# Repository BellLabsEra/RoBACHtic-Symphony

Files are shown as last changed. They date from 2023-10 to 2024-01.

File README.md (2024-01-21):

# RoBACHtic-Symphony
ECE 3011 Design Fundamentals Project

## Project Description

In the realm of junior-design team initiatives, we undertook a project focused on the development of an educational robot kit. This kit, specifically designed for 5th-grade students, imparts comprehensive knowledge on discerning a violin's bow movement, placement, and techniques—particularly bow posture—while performing musical compositions featuring diverse notes. The device seamlessly integrates with a MIDI piano keyboard, utilizing user input to produce two outputs: a robotic arm executing bow movements corresponding to the "mapped" string and an audio sample replicating the played note.

Comprising a team of four students—three specializing in Electrical Engineering and one in Computer Engineering—we dedicated ourselves to the intricate aspects of Mechanical, Electrical, and Software engineering. In conjunction with the hardware and software components, we meticulously crafted four essential artifacts: a Design Document, Bill of Materials (BOM), Lesson Plan, and Notebook. Notably, our Lesson Plan aligns meticulously with the Georgia Standards of Excellence (GSE) for both Music and Computer Science curricula.

In the context of this collaborative effort, I assumed a leadership role in spearheading the software development aspect of the project. This multifaceted undertaking served as the focal point of our endeavors within the framework of ECE 3011 - Design Fundamentals.

### Link to YouTube Video Demonstration: 
https://youtu.be/gud--ybyr-s?si=2pJu3Hc5zI2o3BWv

### Link to Final Document PDF: 
https://github.com/BellLabsEra/RoBACHtic-Symphony/blob/main/ECE3011%20Team%20C2%20Final%20Document%20Package.pdf

Document containing the (1) Design Document,(2) Lesson Plan, and (3) BOM

### Front View Pictures:

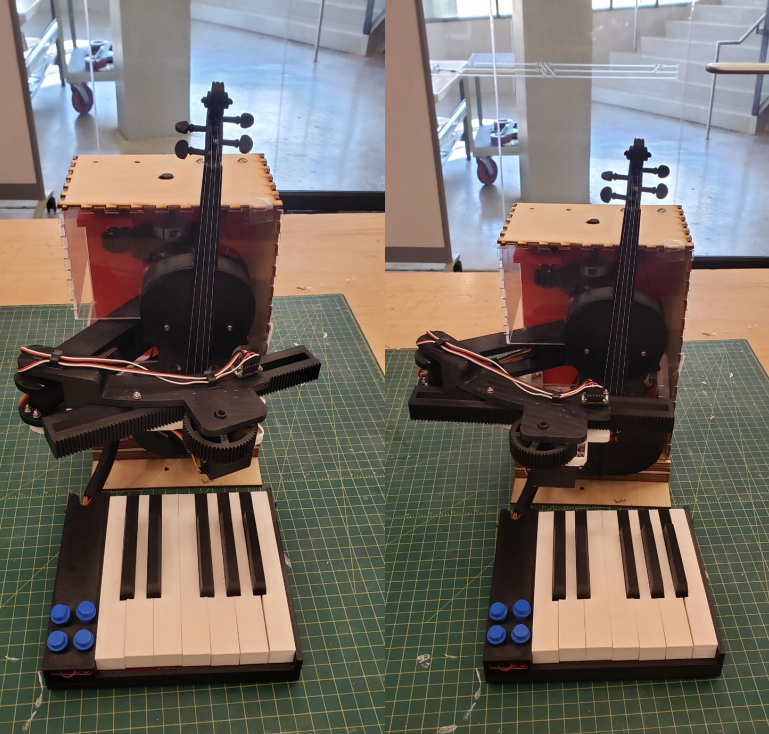
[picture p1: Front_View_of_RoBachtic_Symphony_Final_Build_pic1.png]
Front_View_Pic1


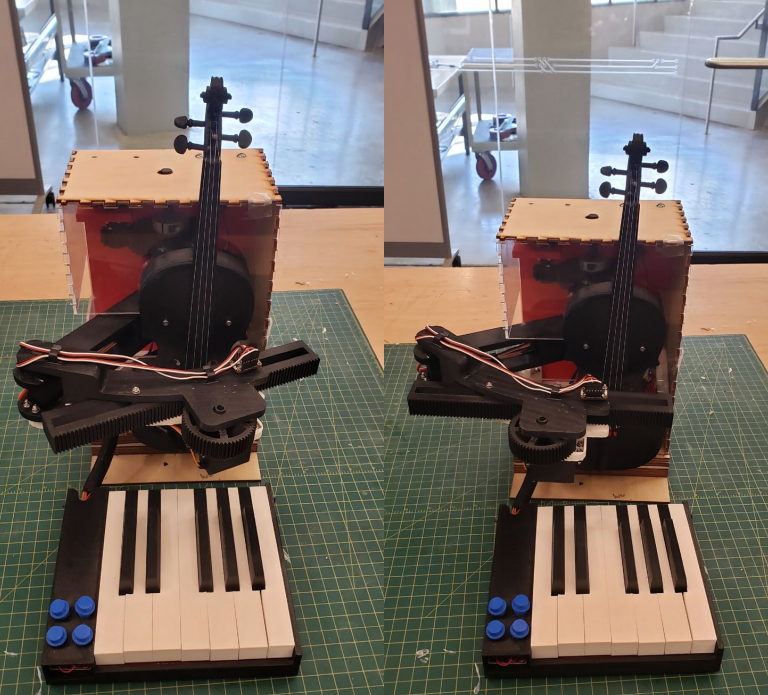
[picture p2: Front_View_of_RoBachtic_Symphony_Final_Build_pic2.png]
Front_View_Pic2


### Labeled Picture:

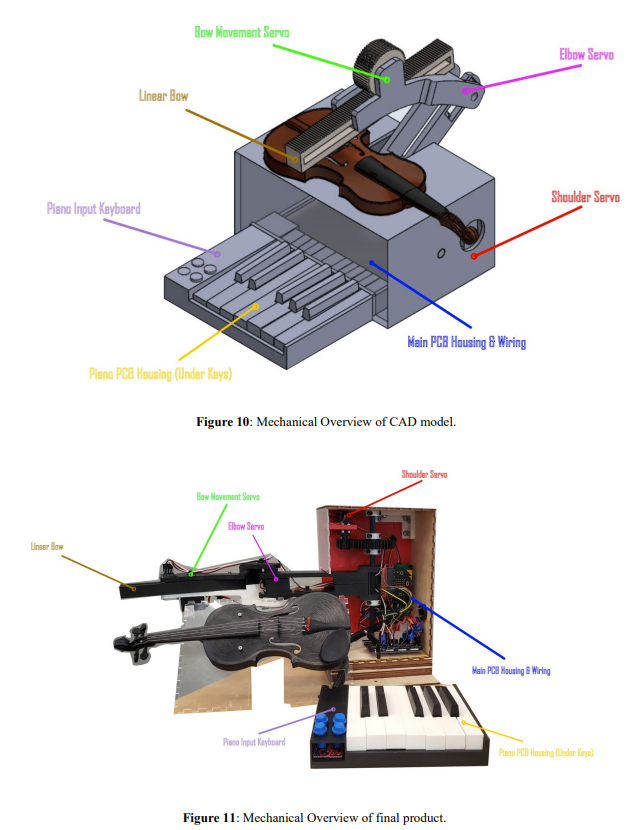
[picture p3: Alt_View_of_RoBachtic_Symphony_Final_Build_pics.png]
Labeled_Picture


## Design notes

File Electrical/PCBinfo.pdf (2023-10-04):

GND1 | Vsupply GND | | V_USED(V) | I_MAX(mA) | I_TOTAL(mA)
GND2 | | PIANO | 3.3 | 8 | 1421
3V3 | IMU,PIANO,MAIN 3.3V | IMU | 3.3 | 5
A0 | PWM SERVO0 | SERVO1 | 6 | 1200 | <-------- | ONLY MOVE ONE AT A TIME
A1 | PWM SERVO1 | SERVO2 | 6 | 0
A2 | PWM SERVO2 | SERVO3 | 6 | 0
A3 | PWM SERVO3 | SERVO4 | 6 | 0
A4 | SPEAKER OUT | LED1 | 3.3 | 2
D5 | LED1 | LED2 | 3.3 | 2
D6 | LED2 | LED3 | 3.3 | 2
D7 | LED3 | LED4 | 3.3 | 2
D8 | LED4 | AMP (0.5W) | 5 | 200
D9
D10 | | | Links
D11 | IMU | https://learn.adafruit.com/adafruit-tdk-invensense-icm-20948-9-dof-imu/pinouts
D12 | IO EXPANDER https://www.digikey.com/en/products/detail/texas-instruments/PCF8575PWE4/1573160
D13 | IMU SCK | SERVOS | https://www.amazon.com/Control-Angle180-Digital-Torque-Helicopter/dp/B07NQJ1VZ2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
D14 | IMU MISO | LEDS | https://www.digikey.com/en/products/detail/sunled/XCMDK12D/13559388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
D15 | IMU MOSI | MONO AMP | https://www.sparkfun.com/products/11044
D16 | IMU CS | PCB PJACK | https://www.sparkfun.com/products/10811
D19 (SCL) | PIANO SCL | VREG | https://www.digikey.com/en/products/detail/stmicroelectronics/LM317T/591677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
D20 (SDA) | PIANO SDA

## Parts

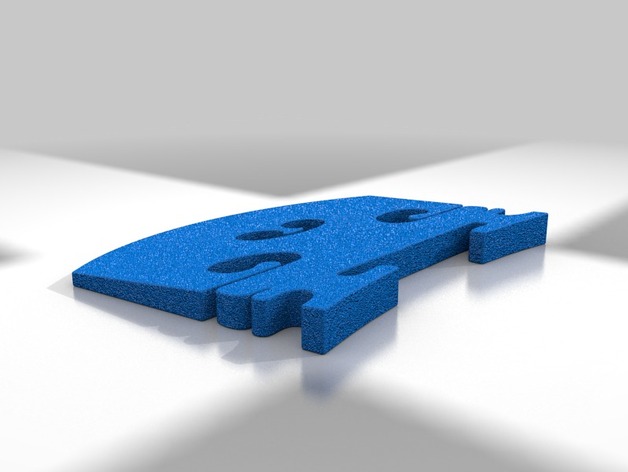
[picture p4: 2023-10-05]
Mechanical Components made by Jeon's blood and tear/images/images/Violin.XIII.Bridge.jpg

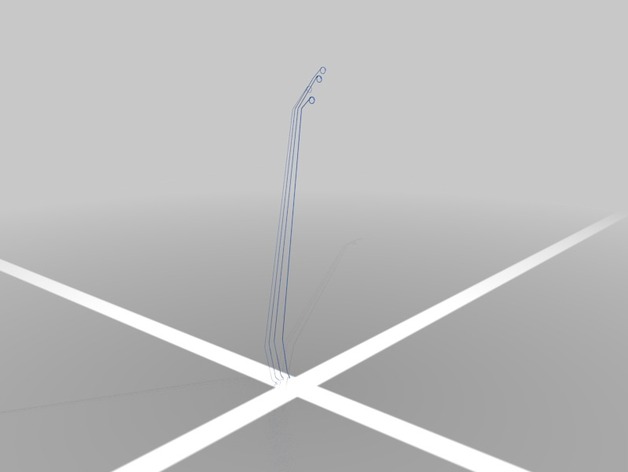
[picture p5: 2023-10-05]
Mechanical Components made by Jeon's blood and tear/images/images/Violin.XIII.Strings.jpg

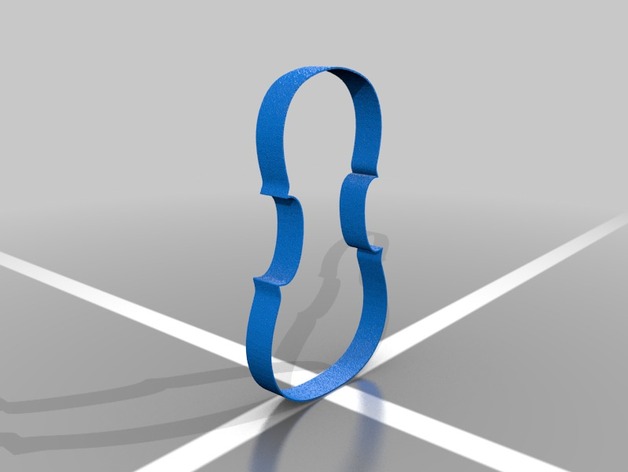
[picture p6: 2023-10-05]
Mechanical Components made by Jeon's blood and tear/images/images/Violin.XIII.Side.jpg

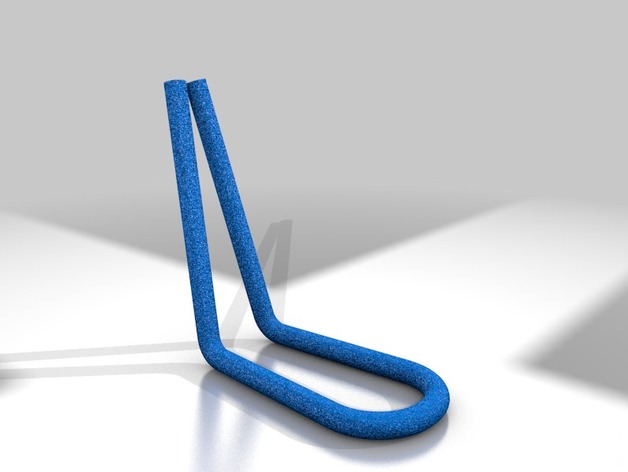
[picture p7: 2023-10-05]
Mechanical Components made by Jeon's blood and tear/images/images/Violin.XIII.Tail.Cord.jpg

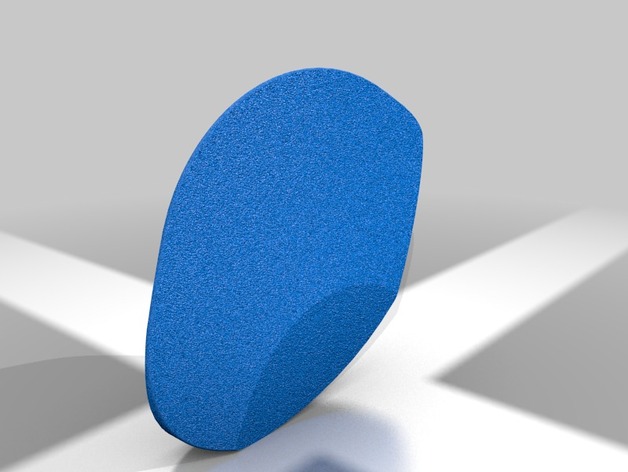
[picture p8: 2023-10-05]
Mechanical Components made by Jeon's blood and tear/images/images/Violin.XIII.Chin.Rest.jpg

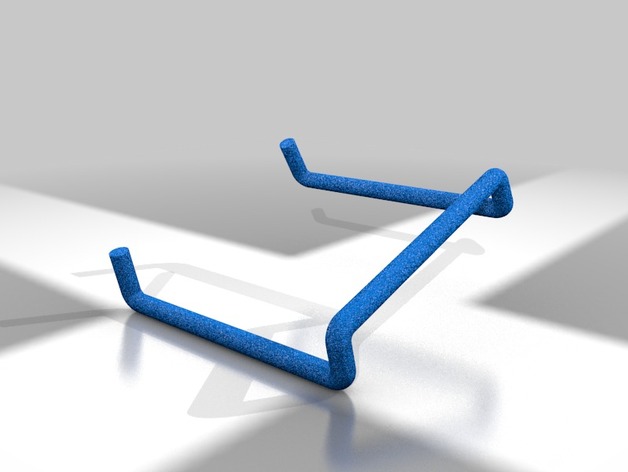
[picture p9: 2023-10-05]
Mechanical Components made by Jeon's blood and tear/images/images/Violin.XIII.Chin.Rest.Clamp.jpg

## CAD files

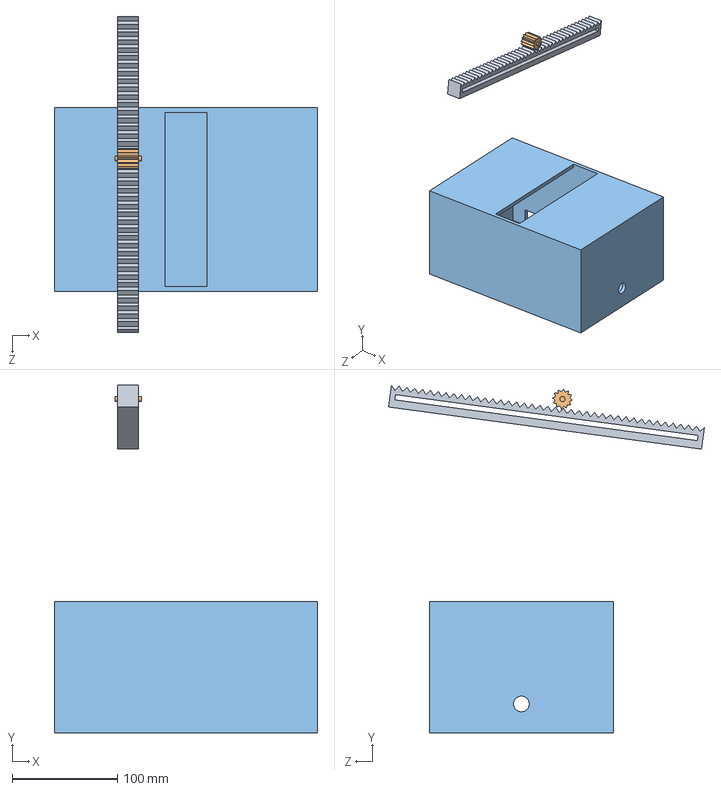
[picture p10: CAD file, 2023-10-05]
Mechanical Components made by Jeon's blood and tear/Prototype_x.SLDASM
250.0 x 330.4 x 300.1 mm
Gear
Bow

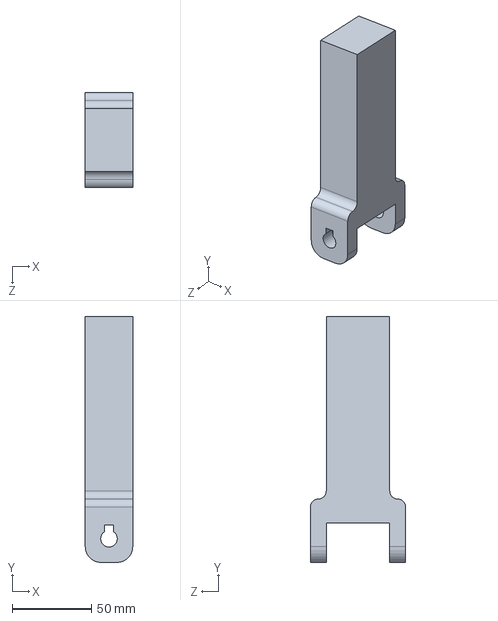
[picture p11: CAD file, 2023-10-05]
Mechanical Components made by Jeon's blood and tear/Arms/Part_Files/MainArm.SLDPRT
30.0 x 155.0 x 60.0 mm

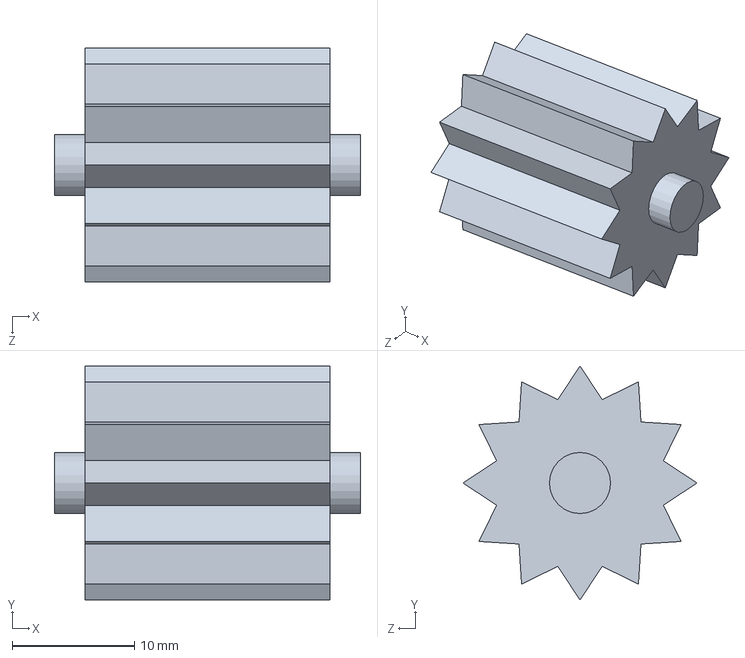
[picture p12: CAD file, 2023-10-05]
Mechanical Components made by Jeon's blood and tear/Arms/Gear.SLDPRT
25.0 x 19.1 x 19.1 mm

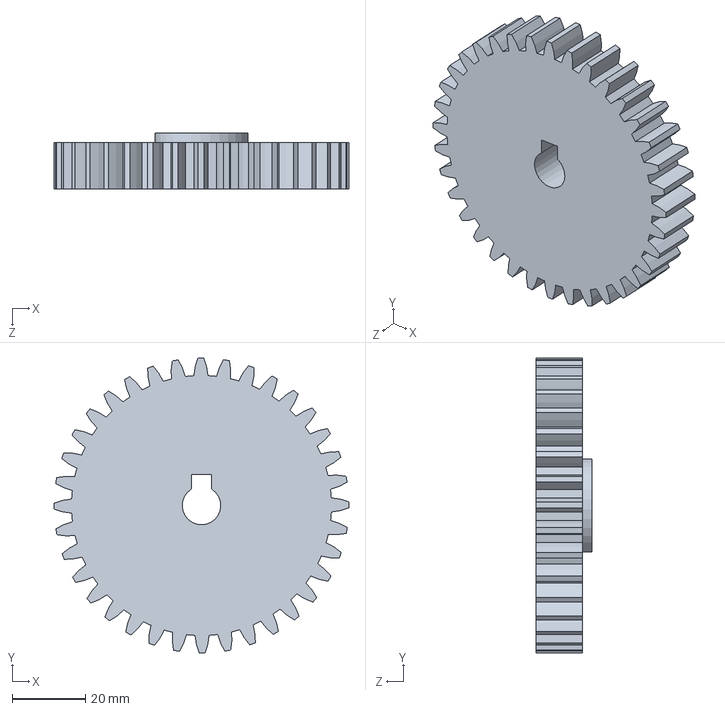
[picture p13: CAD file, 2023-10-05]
Mechanical Components made by Jeon's blood and tear/Arms/Part_Files/LargeGear.SLDPRT
80.4 x 80.4 x 15.2 mm

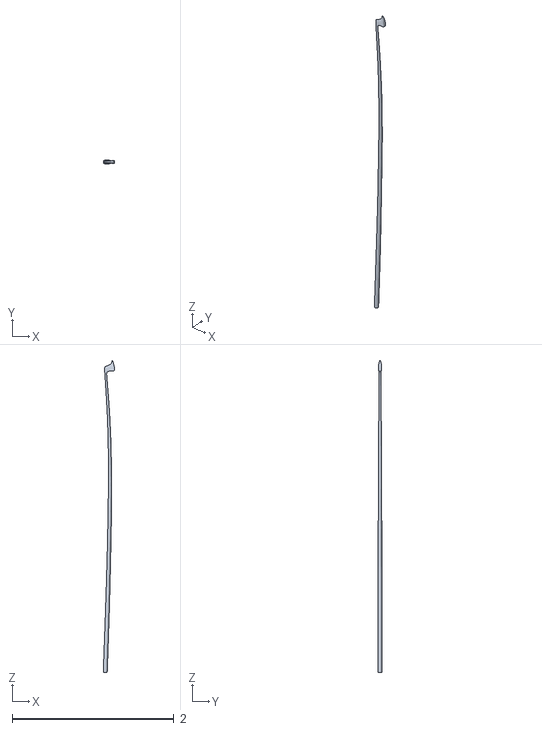
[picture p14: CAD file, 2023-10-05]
Mechanical Components made by Jeon's blood and tear/files/files/Violin.XIII.Bow.Rod.stl
0.142 x 0.0497 x 3.86

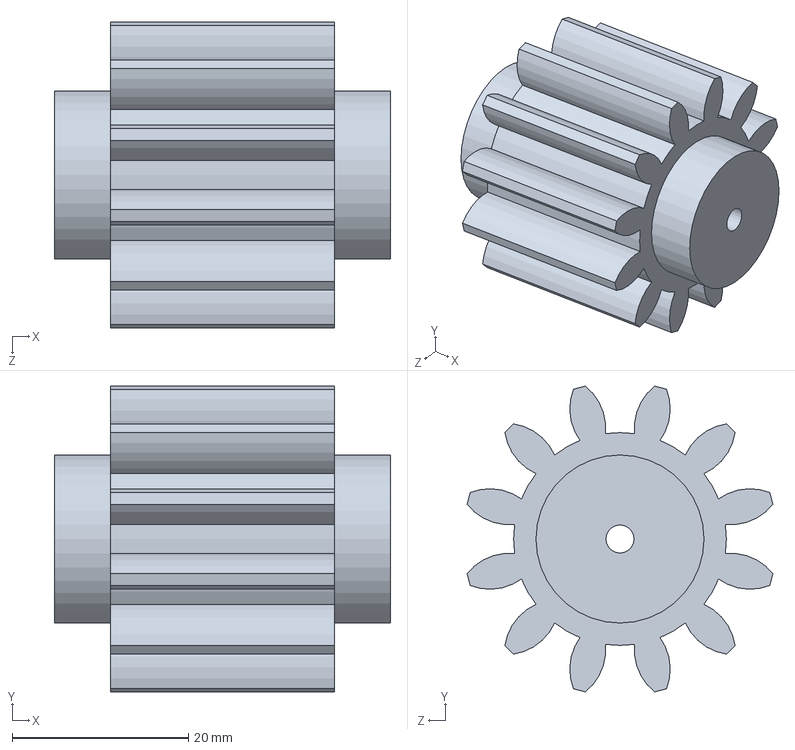
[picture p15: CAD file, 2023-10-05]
Mechanical Components made by Jeon's blood and tear/GearboxMod/SmallGear.SLDPRT
38.1 x 34.7 x 34.7 mm

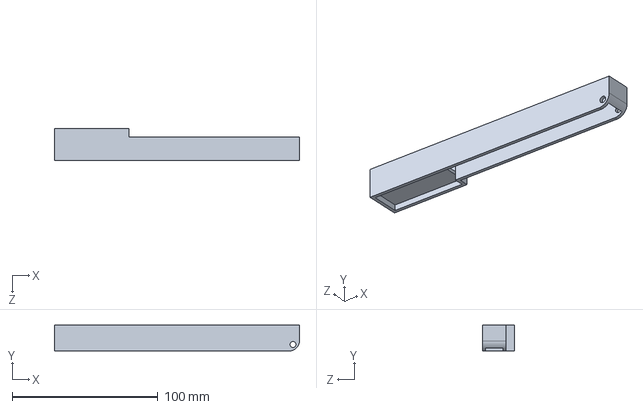
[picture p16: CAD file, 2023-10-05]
Mechanical Components made by Jeon's blood and tear/Keyboard/SLDPRT/White Key L.SLDPRT
168.0 x 17.8 x 22.0 mm

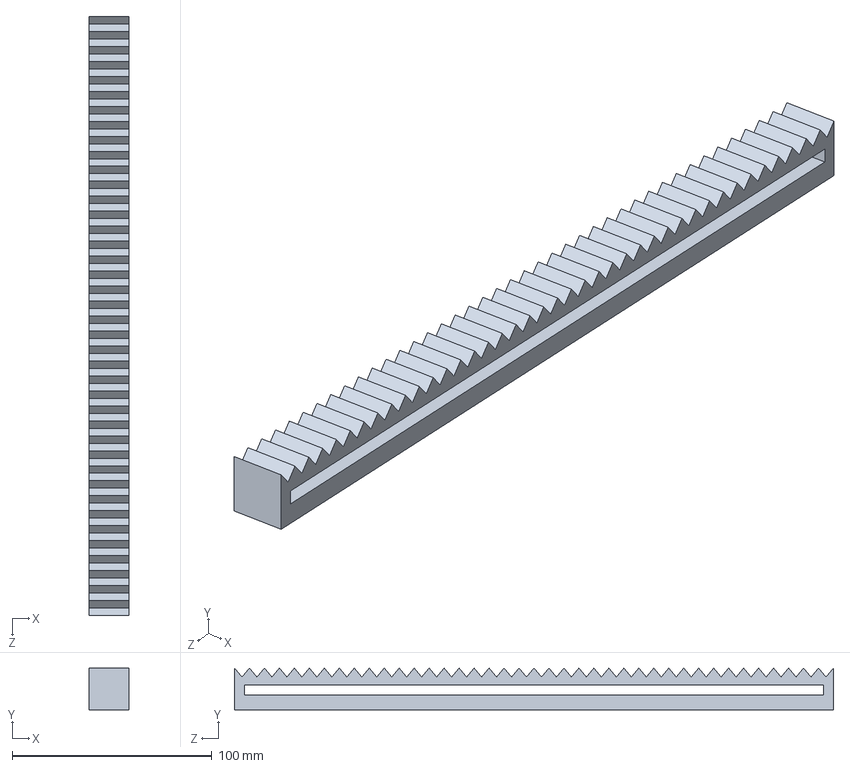
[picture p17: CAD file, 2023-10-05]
Mechanical Components made by Jeon's blood and tear/Arms/Bow.SLDPRT
20.0 x 21.0 x 300.0 mm

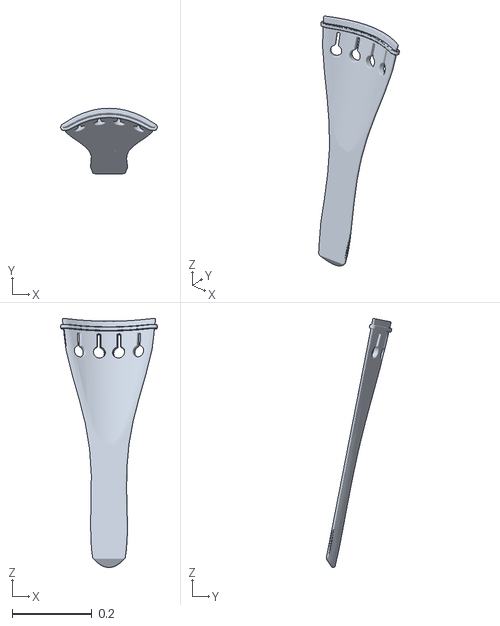
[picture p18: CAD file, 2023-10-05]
Mechanical Components made by Jeon's blood and tear/files/files/Violin.XIII.Tail.Piece.stl
0.243 x 0.165 x 0.626

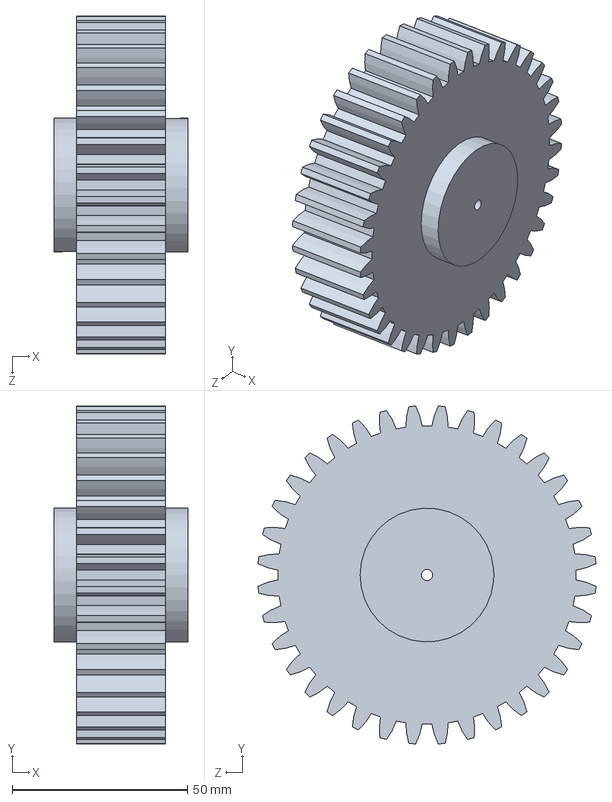
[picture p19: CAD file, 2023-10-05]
Mechanical Components made by Jeon's blood and tear/GearboxMod/LargeGear.SLDPRT
38.1 x 96.3 x 96.3 mm

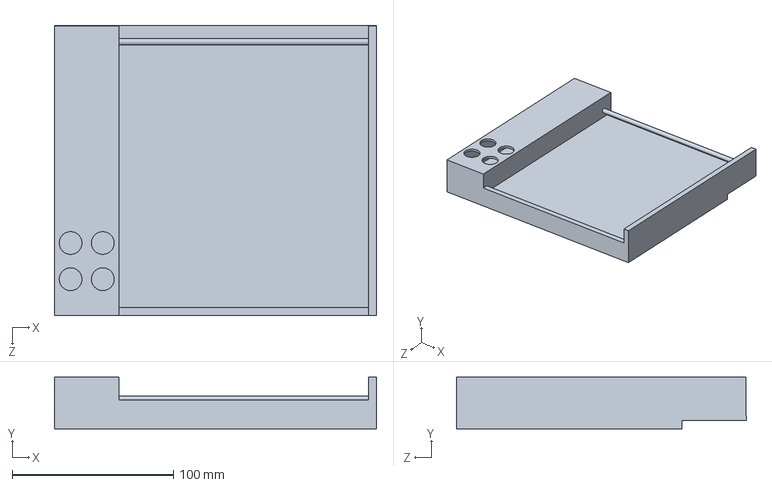
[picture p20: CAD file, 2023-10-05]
Mechanical Components made by Jeon's blood and tear/Keyboard/SLDPRT/Keyboard Box.SLDPRT
200.0 x 32.0 x 180.0 mm

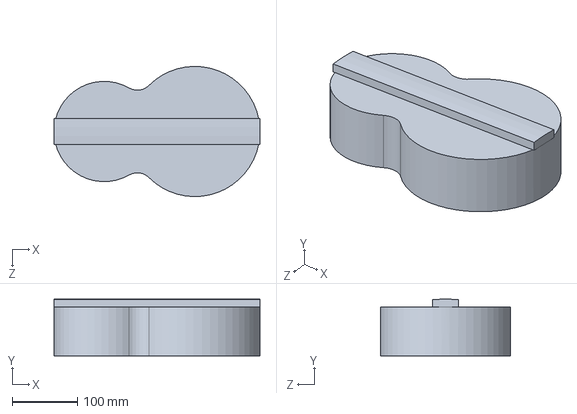
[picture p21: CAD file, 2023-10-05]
Mechanical Components made by Jeon's blood and tear/Violin_x.SLDPRT
316.5 x 87.1 x 200.0 mm

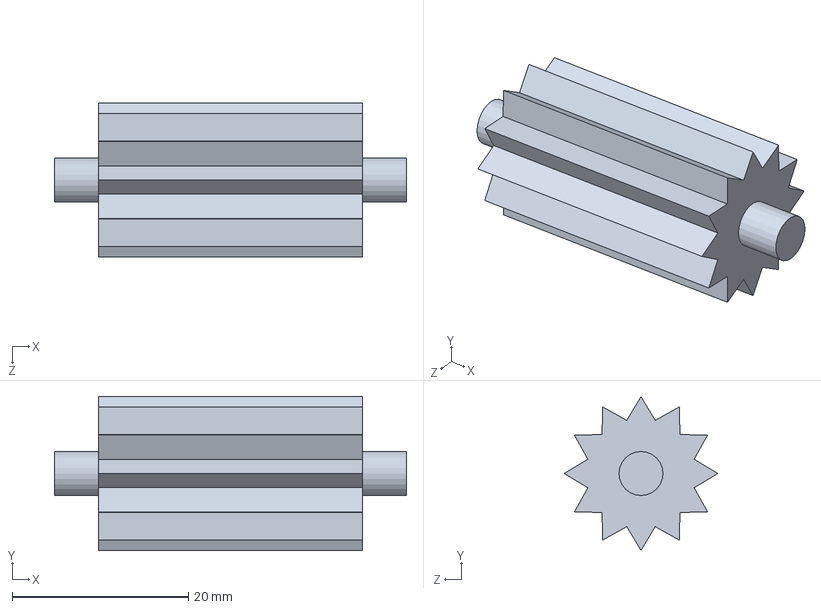
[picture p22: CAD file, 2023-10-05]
Mechanical Components made by Jeon's blood and tear/Arms/Gear_x.SLDPRT
40.0 x 17.5 x 17.5 mm

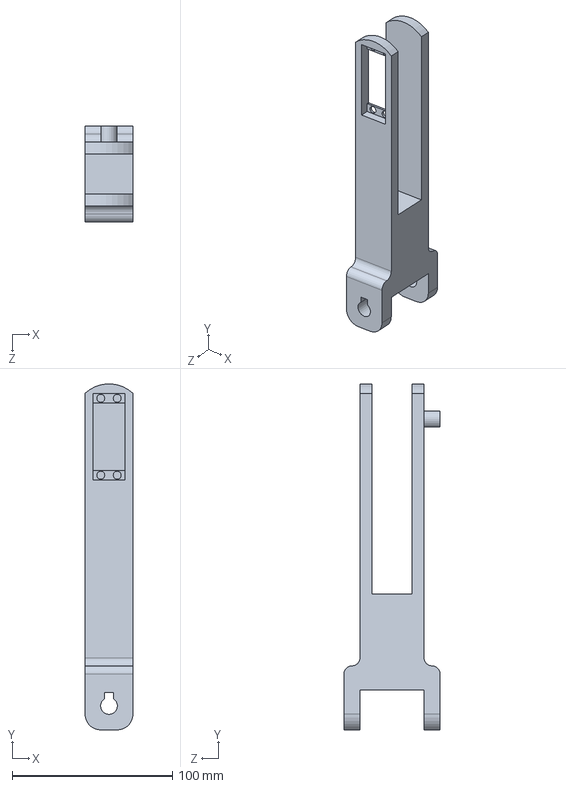
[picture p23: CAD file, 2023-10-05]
Mechanical Components made by Jeon's blood and tear/Arms/Part_Files/Biceps(2).SLDPRT
30.0 x 215.9 x 60.0 mm

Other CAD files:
Mechanical Components made by Jeon's blood and tear/Arms/Part_Files/GearAssembly.SLDASM
Mechanical Components made by Jeon's blood and tear/Prototype_xx.SLDASM
Mechanical Components made by Jeon's blood and tear/Prototype.SLDASM
Mechanical Components made by Jeon's blood and tear/Box.SLDPRT
Mechanical Components made by Jeon's blood and tear/Arms/Arm.SLDPRT
Mechanical Components made by Jeon's blood and tear/Arms/Arm_x.SLDPRT
Mechanical Components made by Jeon's blood and tear/Arms/Part_Files/Bow Gear.SLDPRT
Mechanical Components made by Jeon's blood and tear/Arms/Part_Files/Bow.SLDPRT
Mechanical Components made by Jeon's blood and tear/Arms/Part_Files/Forearm.SLDPRT
Mechanical Components made by Jeon's blood and tear/Arms/Part_Files/SmallGear.SLDPRT
Mechanical Components made by Jeon's blood and tear/Arms/Part_Files/shaft.SLDPRT
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

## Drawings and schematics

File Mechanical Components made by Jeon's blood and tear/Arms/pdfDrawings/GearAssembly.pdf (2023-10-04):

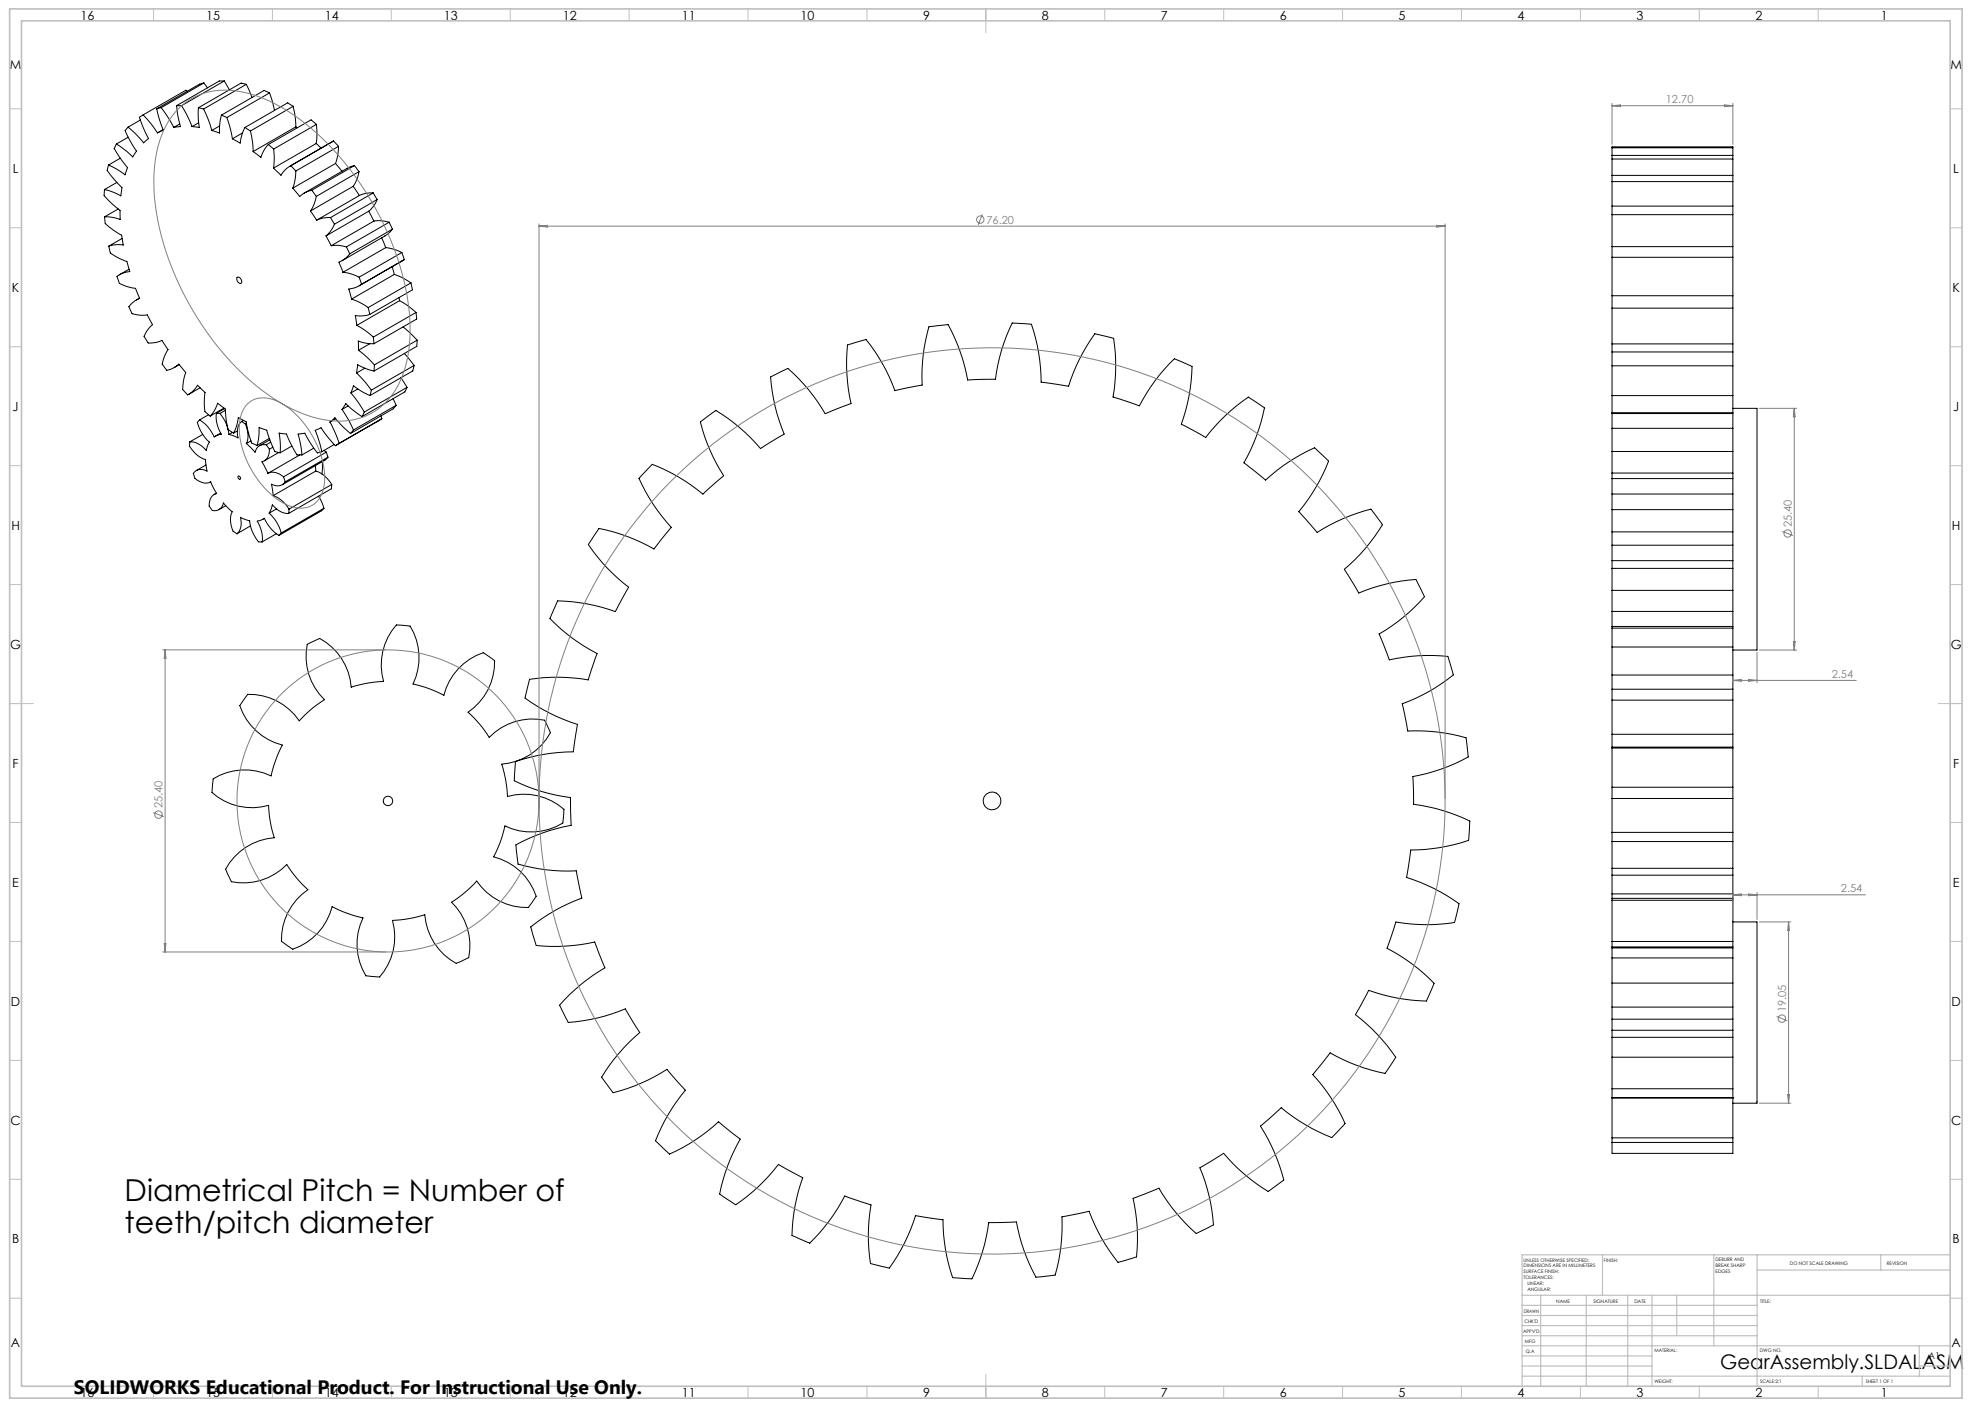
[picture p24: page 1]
FINISH:; DEBURR AND; BREAK SHARP; DO NOT SCALE DRAWING; REVISION; SCALE:2:1; SHEET 1 OF 1

Diametrical Pitch = Number of
teeth/pitch diameter

UNLESS OTHERWISE SPECIFIED:
DIMENSIONS ARE IN MILLIMETERS
SURFACE FINISH:
TOLERANCES:
LINEAR:
ANGULAR:

NAME | SIGNATURE | DATE | | | | TITLE:

DRAWN
CHK'D
APPV'D
MFG
Q.A | | | | MATERIAL: | DWG NO. | A1

SOLIDWORKS Educational Product. For Instructional Use Only.

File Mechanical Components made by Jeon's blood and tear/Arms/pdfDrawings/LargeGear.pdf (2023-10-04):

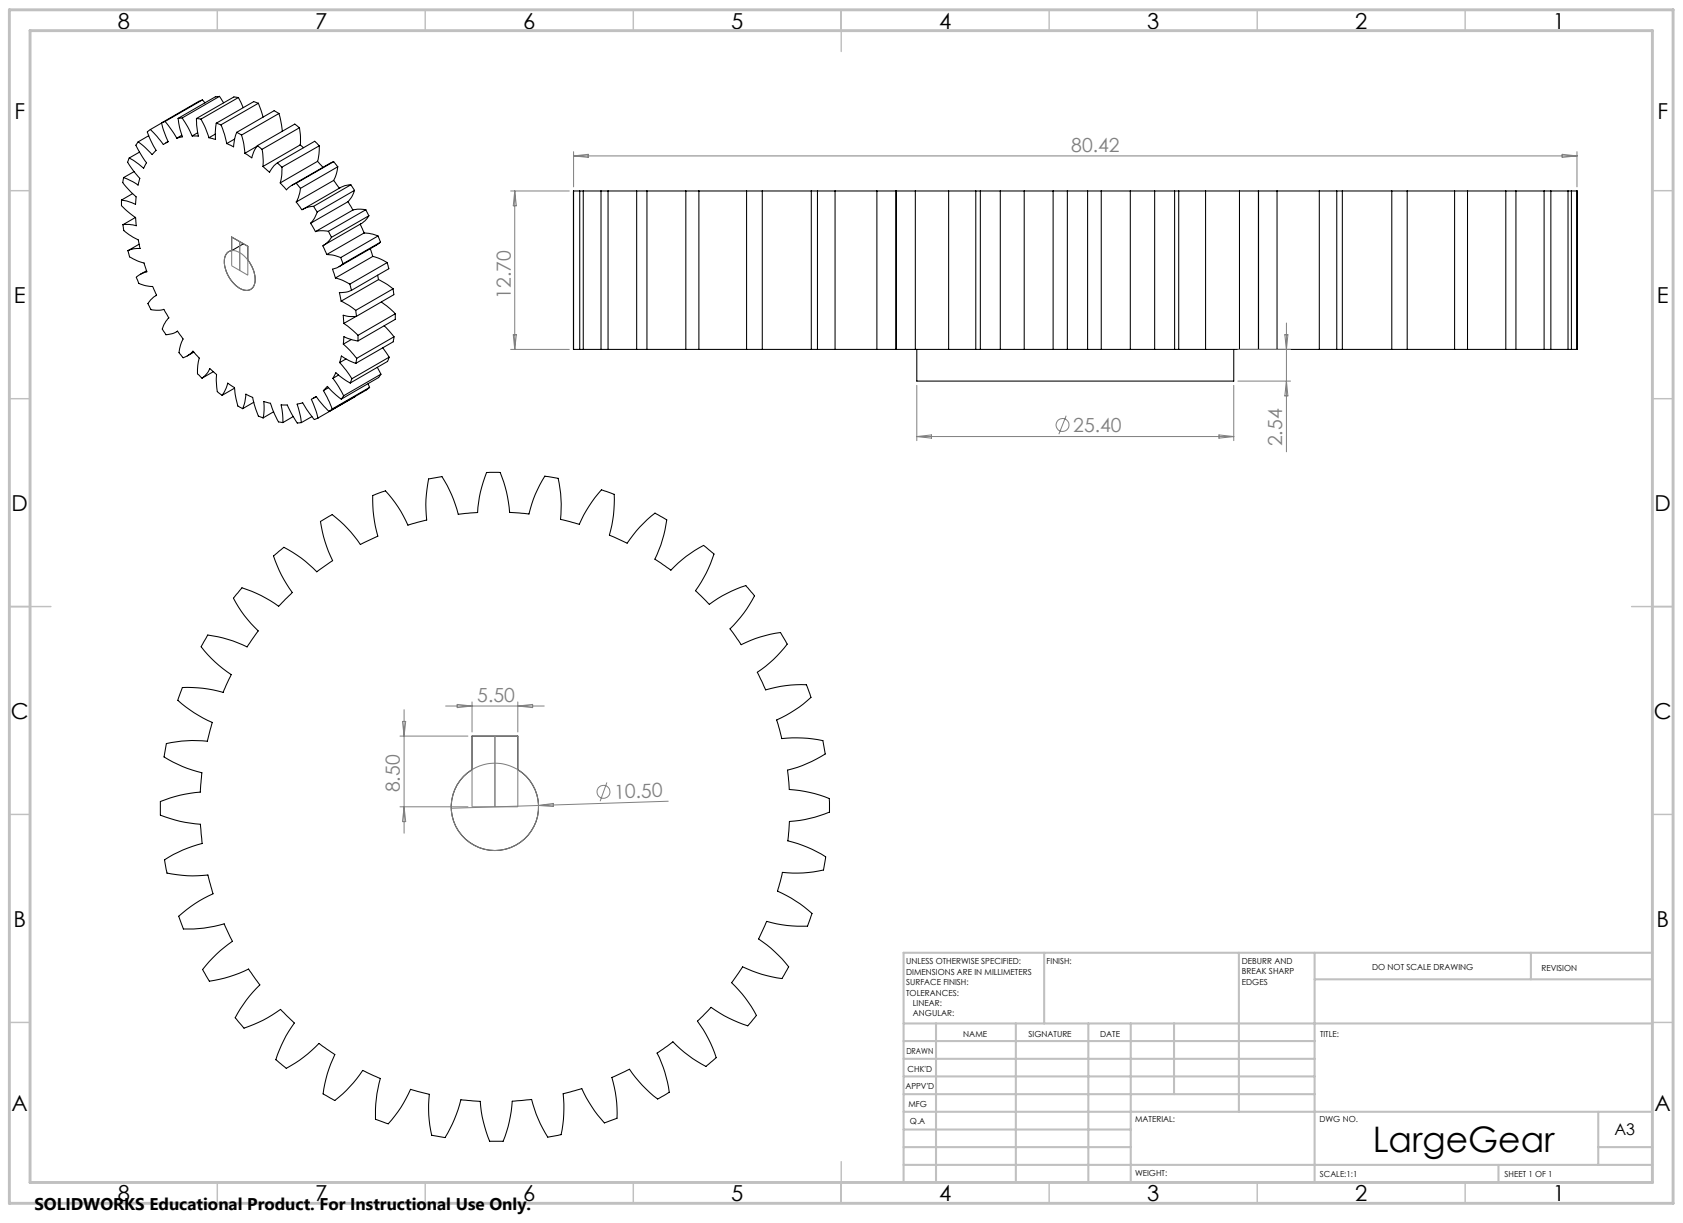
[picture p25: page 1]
FINISH:; DEBURR AND; BREAK SHARP; DO NOT SCALE DRAWING; REVISION; SCALE:1:1; SHEET 1 OF 1

UNLESS OTHERWISE SPECIFIED:
DIMENSIONS ARE IN MILLIMETERS
SURFACE FINISH:
TOLERANCES:
LINEAR:
ANGULAR:

NAME | SIGNATURE | DATE | | | | TITLE:

DRAWN
CHK'D
APPV'D
MFG
Q.A | | | | MATERIAL: | DWG NO. LargeGear | A3

SOLIDWORKS Educational Product. For Instructional Use Only.

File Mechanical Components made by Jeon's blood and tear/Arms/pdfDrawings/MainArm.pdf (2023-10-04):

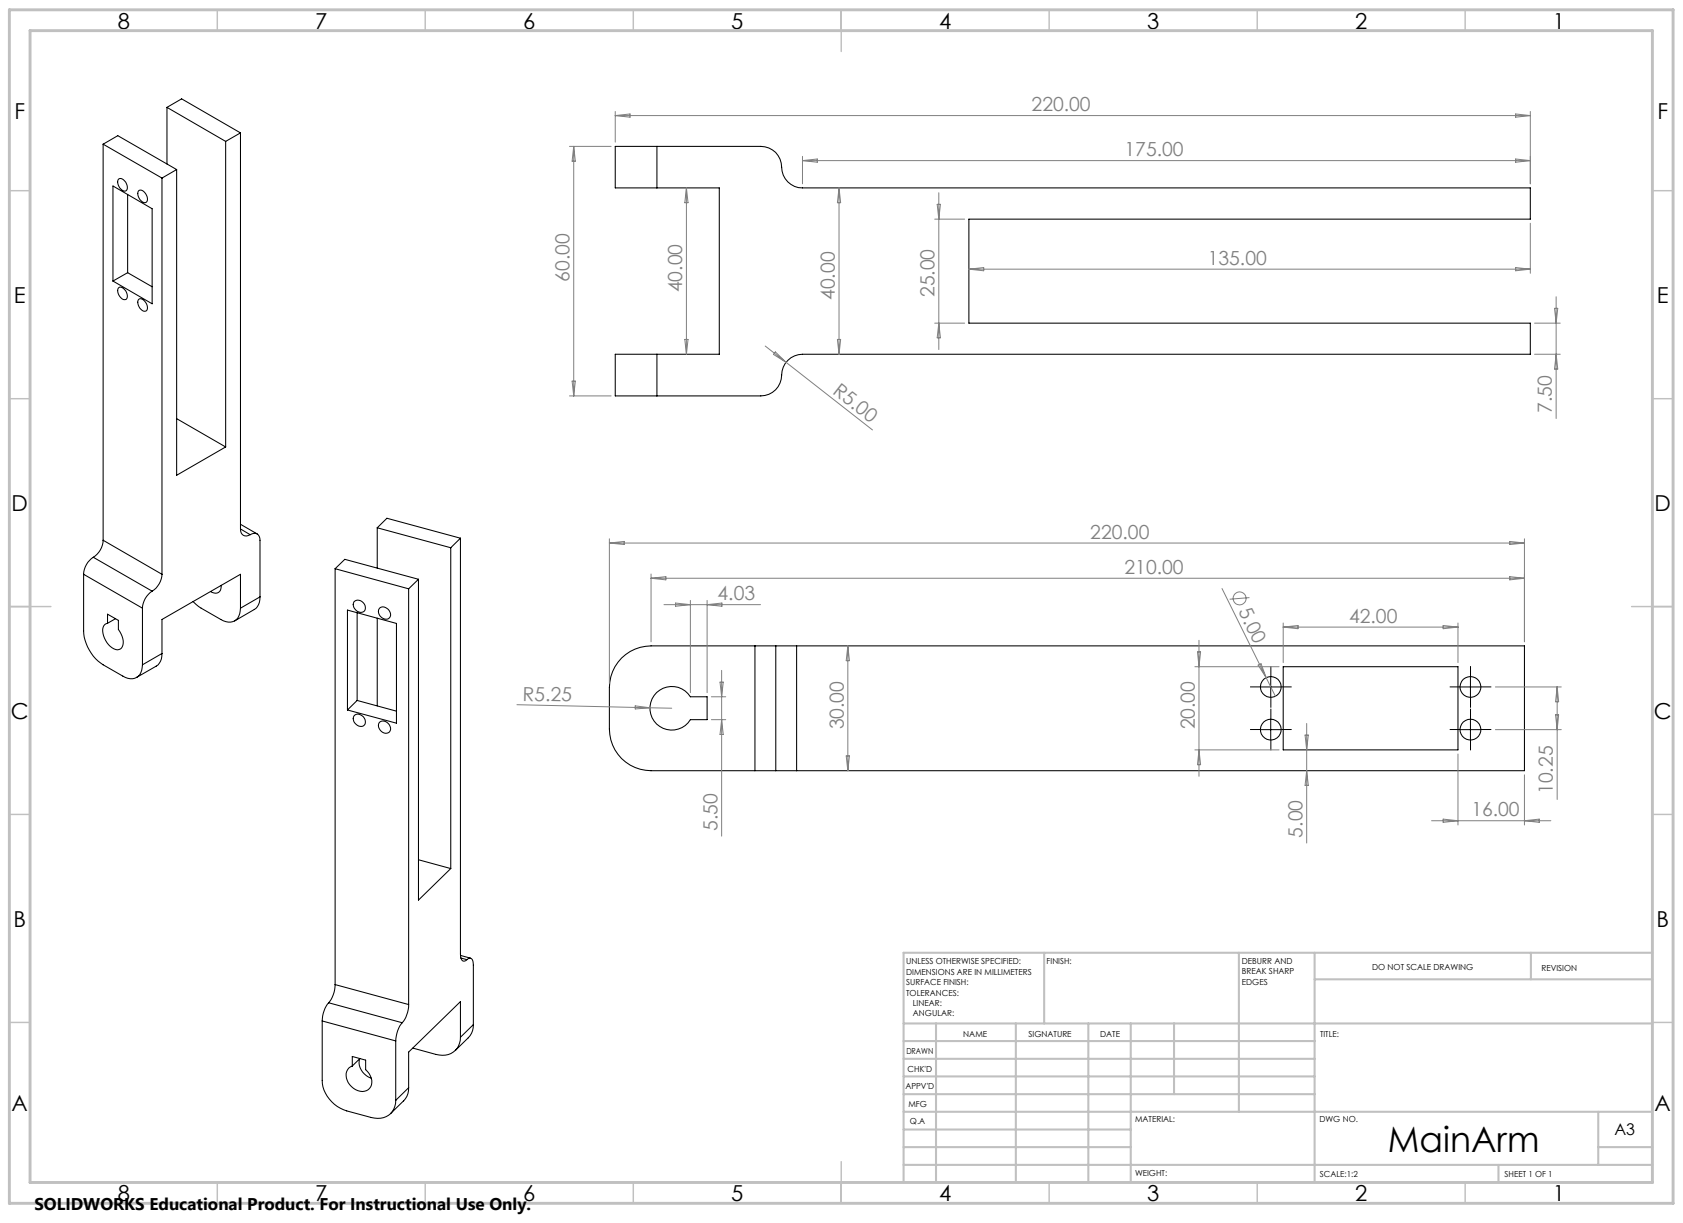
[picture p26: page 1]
FINISH:; DEBURR AND; BREAK SHARP; DO NOT SCALE DRAWING; REVISION; SCALE:1:2; SHEET 1 OF 1

UNLESS OTHERWISE SPECIFIED:
DIMENSIONS ARE IN MILLIMETERS
SURFACE FINISH:
TOLERANCES:
LINEAR:
ANGULAR:

NAME | SIGNATURE | DATE | | | | TITLE:

DRAWN
CHK'D
APPV'D
MFG
Q.A | | | | MATERIAL: | DWG NO. MainArm | A3

SOLIDWORKS Educational Product. For Instructional Use Only.

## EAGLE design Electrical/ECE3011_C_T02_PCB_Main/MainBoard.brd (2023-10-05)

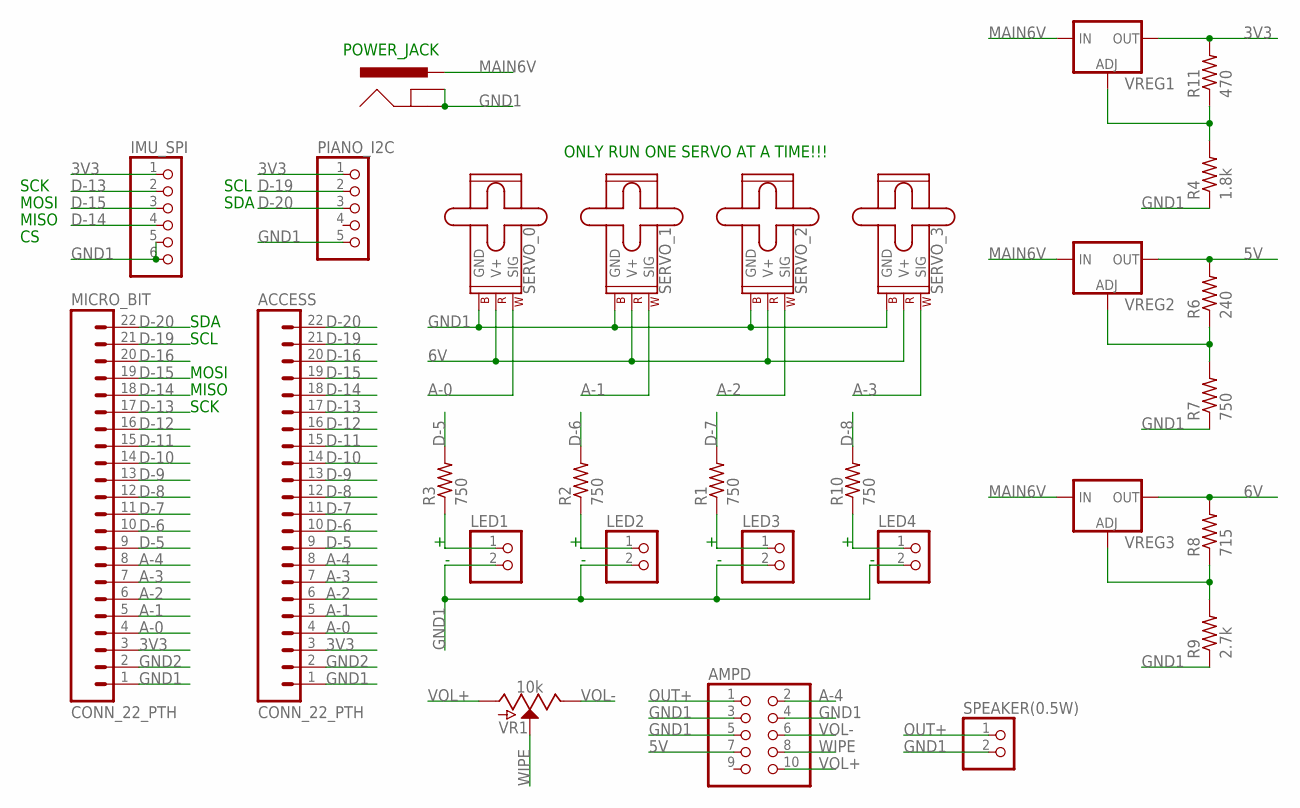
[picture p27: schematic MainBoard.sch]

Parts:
ACCESS: CONN_22_PTH; 1X22
AMPD: PINHD-2X5; 2X05
IMU_SPI: PINHD-1X6; 1X06
LED1, LED2, LED3, LED4: PINHD-1X2; 1X02
MICRO_BIT: CONN_22_PTH; 1X22
PIANO_I2C: PINHD-1X5; 1X05
POWER_JACK: POWER_JACKPTH_BREAD; POWER_JACK_PTH_BREAD
R1, R2, R3, R7, R10: 750; 0207/10
R4: 1.8k; 0207/10
R6: 240; 0207/10
R8: 715; 0207/10
R9: 2.7k; 0207/10
R11: 470; 0207/10
SERVO_0, SERVO_1, SERVO_2, SERVO_3: SERVO; 1X03
SPEAKER(0.5W): PINHD-1X2; 1X02
VR1: 10k; POT-PTH-ALPS
VREG1, VREG2, VREG3: V_REG_317SINK; TO220-ADJ

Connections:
3V3: ACCESS.3, IMU_SPI.1, MICRO_BIT.3, PIANO_I2C.1, R11.2, VREG1.OUT
5V: AMPD.7, R6.2, VREG2.OUT
6V: R8.2, SERVO_0.2 (V+), SERVO_1.2 (V+), SERVO_2.2 (V+), SERVO_3.2 (V+), VREG3.OUT
A-0: ACCESS.4, MICRO_BIT.4, SERVO_0.1 (SIG)
A-1: ACCESS.5, MICRO_BIT.5, SERVO_1.1 (SIG)
A-2: ACCESS.6, MICRO_BIT.6, SERVO_2.1 (SIG)
A-3: ACCESS.7, MICRO_BIT.7, SERVO_3.1 (SIG)
A-4: ACCESS.8, AMPD.2, MICRO_BIT.8
D-5: ACCESS.9, MICRO_BIT.9, R3.2
D-6: ACCESS.10, MICRO_BIT.10, R2.2
D-7: ACCESS.11, MICRO_BIT.11, R1.2
D-8: ACCESS.12, MICRO_BIT.12, R10.2
D-9: ACCESS.13, MICRO_BIT.13
D-10: ACCESS.14, MICRO_BIT.14
D-11: ACCESS.15, MICRO_BIT.15
D-12: ACCESS.16, MICRO_BIT.16
D-13: ACCESS.17, IMU_SPI.2, MICRO_BIT.17
D-14: ACCESS.18, IMU_SPI.4, MICRO_BIT.18
D-15: ACCESS.19, IMU_SPI.3, MICRO_BIT.19
D-16: ACCESS.20, MICRO_BIT.20
D-19: ACCESS.21, MICRO_BIT.21, PIANO_I2C.2
D-20: ACCESS.22, MICRO_BIT.22, PIANO_I2C.3
GND1: ACCESS.1, AMPD.3, AMPD.4, AMPD.5, IMU_SPI.5, IMU_SPI.6, LED1.2, LED2.2, LED3.2, LED4.2, MICRO_BIT.1, PIANO_I2C.5, POWER_JACK.GND, POWER_JACK.GNDBREAK, R4.1, R7.1, R9.1, SERVO_0.3 (GND), SERVO_1.3 (GND), SERVO_2.3 (GND), SERVO_3.3 (GND), SPEAKER(0.5W).2
GND2: ACCESS.2, MICRO_BIT.2
MAIN6V: POWER_JACK.PWR, VREG1.IN, VREG2.IN, VREG3.IN
unnamed: LED1.1, R3.1
unnamed: LED2.1, R2.1
unnamed: LED3.1, R1.1
unnamed: LED4.1, R10.1
unnamed: R4.2, R11.1, VREG1.ADJ
unnamed: R6.1, R7.2, VREG2.ADJ
unnamed: R8.1, R9.2, VREG3.ADJ
OUT+: AMPD.1, SPEAKER(0.5W).1
VOL+: AMPD.10, VR1.P$3 (A)
VOL-: AMPD.6, VR1.P$1 (E)
WIPE: AMPD.8, VR1.P$2 (S)

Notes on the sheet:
SDA
SCL
MOSI
MISO
SCK
ONLY RUN ONE SERVO AT A TIME!!!
POWER_JACK

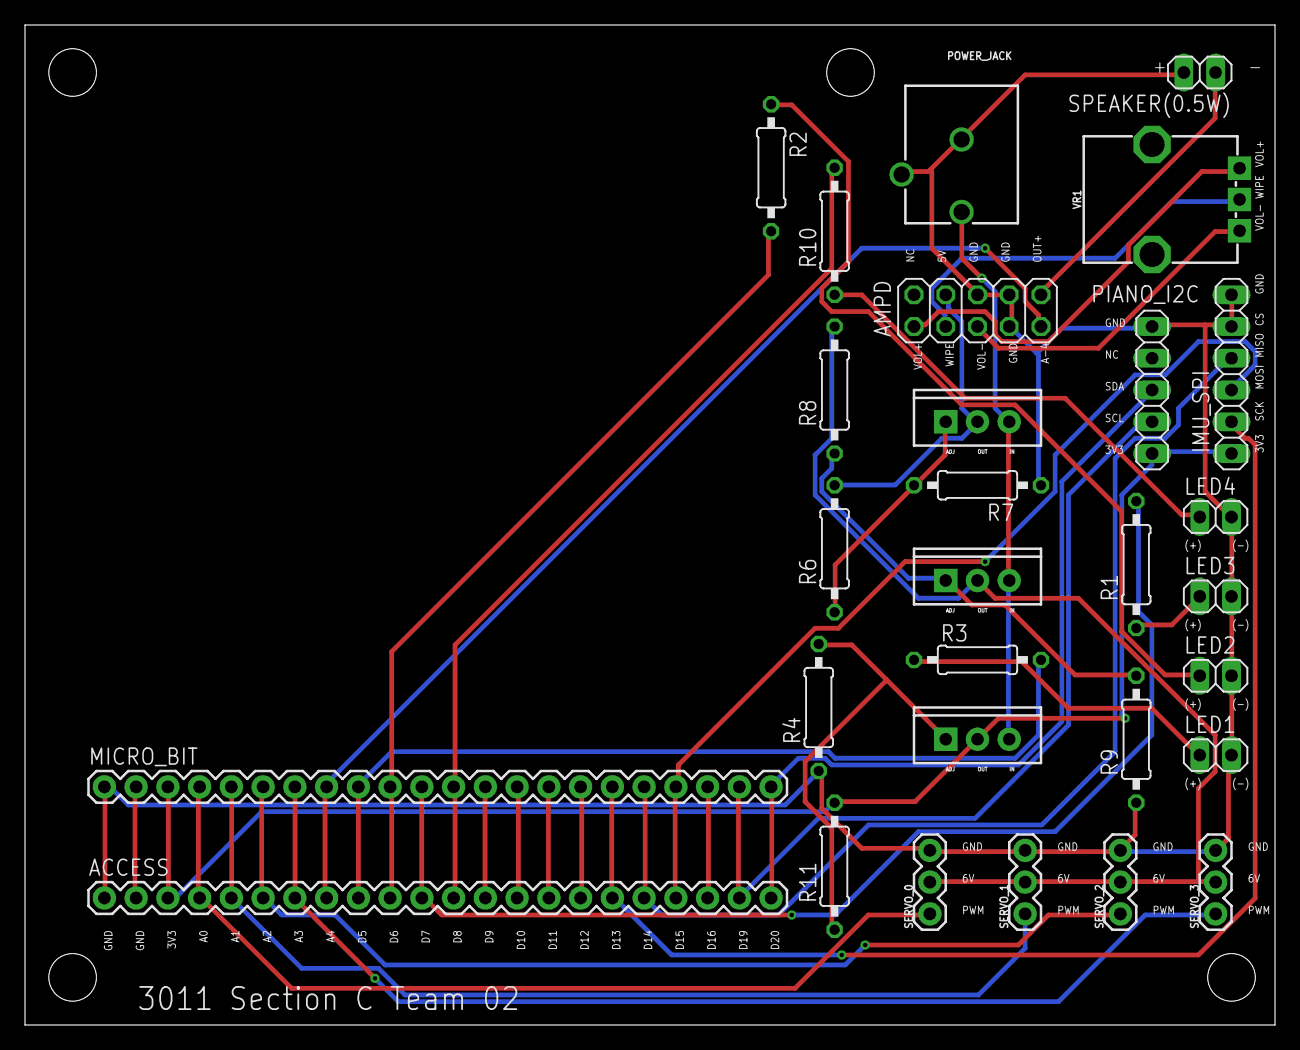
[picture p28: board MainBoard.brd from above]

Board: 2 copper layers, 100.0 x 80.0 mm, 29 parts (0 on the bottom side), 36 nets.

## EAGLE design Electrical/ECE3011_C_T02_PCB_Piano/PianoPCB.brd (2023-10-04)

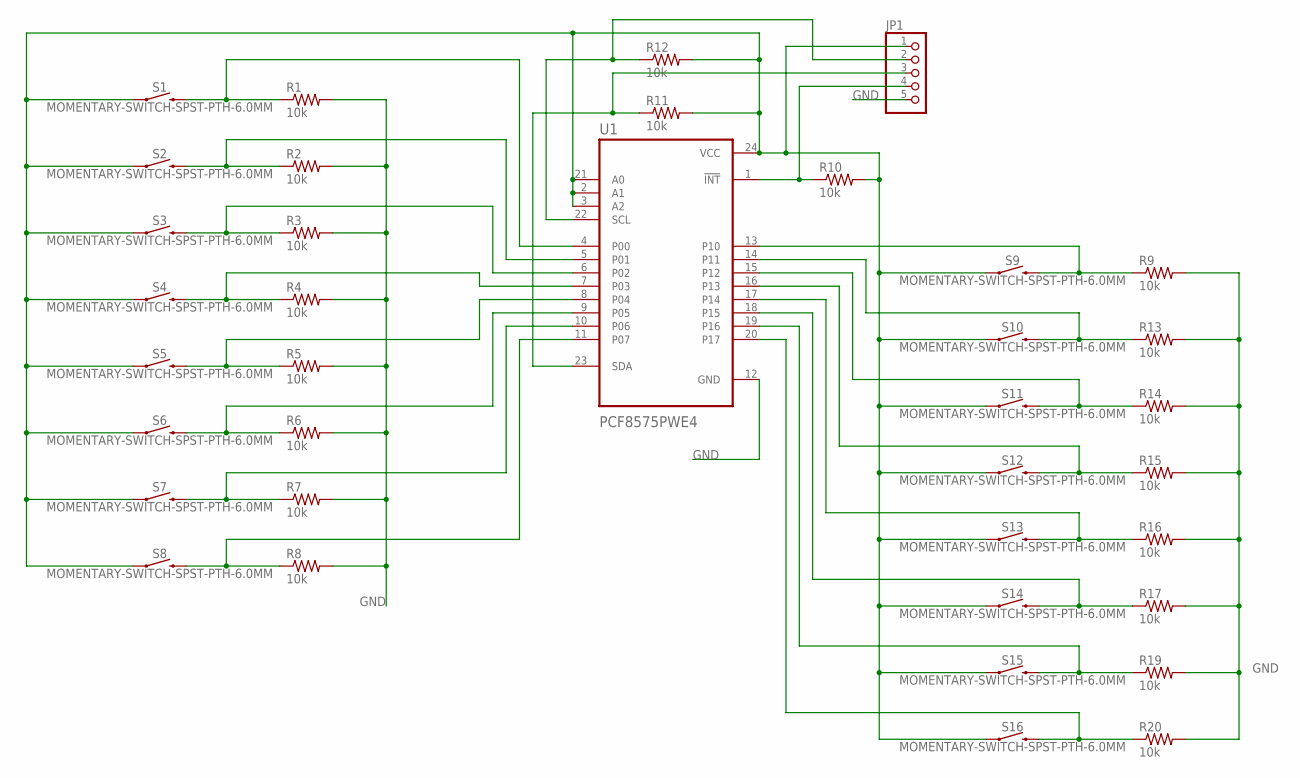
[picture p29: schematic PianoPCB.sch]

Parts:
JP1: PINHD-1X5; 1X05
R1, R2, R3, R4, R5, R6, R7, R8, R9, R10, R11, R12, R13, R14, R15, R16, R17, R19, R20: 10k; 0207/10
S1, S2, S3, S4, S5, S6, S7, S8, S9, S10, S11, S12, S13, S14, S15, S16: MOMENTARY-SWITCH-SPST-PTH-6.0MM; TACTILE_SWITCH_PTH_6.0MM
U1: PCF8575PWE4; SOP65P640X120-24N

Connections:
GND: JP1.5, R1.2, R2.2, R3.2, R4.2, R5.2, R6.2, R7.2, R8.2, R9.2, R13.2, R14.2, R15.2, R16.2, R17.2, R19.2, R20.2, U1.12 (GND)
unnamed: JP1.4, R10.1, U1.1 (!INT)
unnamed: R1.1, S1.3 (2), U1.4 (P00)
unnamed: R2.1, S2.3 (2), U1.5 (P01)
unnamed: R3.1, S3.3 (2), U1.6 (P02)
unnamed: R4.1, S4.3 (2), U1.7 (P03)
unnamed: R5.1, S5.3 (2), U1.8 (P04)
unnamed: R6.1, S6.3 (2), U1.9 (P05)
unnamed: R7.1, S7.3 (2), U1.10 (P06)
unnamed: R8.1, S8.3 (2), U1.11 (P07)
unnamed: R16.1, S13.3 (2), U1.17 (P14)
unnamed: JP1.3, R11.1, U1.23 (SDA)
unnamed: JP1.2, R12.1, U1.22 (SCL)
unnamed: R17.1, S14.3 (2), U1.18 (P15)
unnamed: R20.1, S16.3 (2), U1.20 (P17)
unnamed: R19.1, S15.3 (2), U1.19 (P16)
unnamed: R14.1, S11.3 (2), U1.15 (P12)
unnamed: R9.1, S9.3 (2), U1.13 (P10)
unnamed: R13.1, S10.3 (2), U1.14 (P11)
unnamed: R15.1, S12.3 (2), U1.16 (P13)
VCC1: JP1.1, R10.2, R11.2, R12.2, S1.1, S2.1, S3.1, S4.1, S5.1, S6.1, S7.1, S8.1, S9.1, S10.1, S11.1, S12.1, S13.1, S14.1, S15.1, S16.1, U1.2 (A1), U1.3 (A2), U1.21 (A0), U1.24 (VCC)

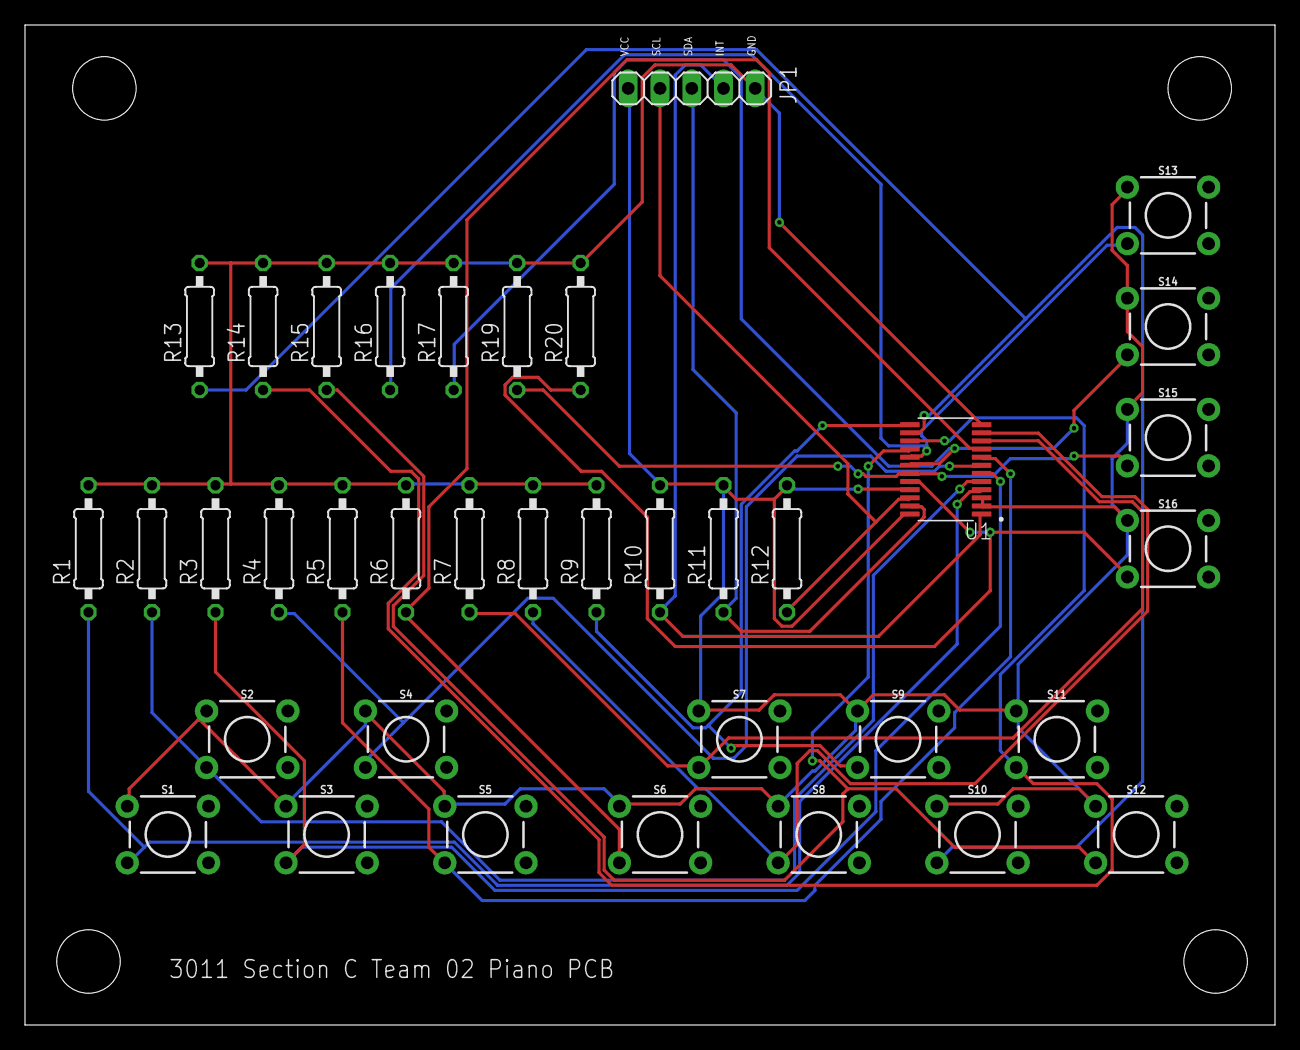
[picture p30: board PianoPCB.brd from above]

Board: 2 copper layers, 100.0 x 80.0 mm, 37 parts (0 on the bottom side), 21 nets.

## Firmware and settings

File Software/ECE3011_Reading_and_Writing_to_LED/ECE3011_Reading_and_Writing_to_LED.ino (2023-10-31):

#define GPIO1 23


int val = 0;
void setup() {
  // put your setup code here, to run once:
  pinMode(GPIO1, INPUT);
}

void loop() {
  // put your main code here, to run repeatedly:
  val = digitalRead(GPIO1);
  if(val == 1) {
    digitalWrite(13, 1);
  } else {
    digitalWrite(13, 0);
  }
  delay(500);
}

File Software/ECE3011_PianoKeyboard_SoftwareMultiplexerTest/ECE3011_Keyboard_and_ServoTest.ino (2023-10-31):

#include <Servo.h>

// Piano Keyboard Inputs
// ----------------------
#define GPIO1 23
#define GPIO2 22
#define GPIO3 24
#define GPIO4 26
#define GPIO5 28
#define GPIO6 30
#define GPIO7 32
#define GPIO8 34
#define GPIO9 36
#define GPIO10 38
#define GPIO11 40
#define GPIO12 42

// Wrist Joint/ Bow Positions
// ---------------------------
#define LEGATTO_UP_BOW_ANGLE 
#define STACCATO_UP_BOW_ANGLE 
#define LEGATTO_STACCATO_DOWN_BOW_ANGLE 

// Elbow Joint Angles corresponding to the Violin string
// ------------------------------------------------------
#define E_STRING_ELBOW_ANGLE
#define A_STRING_ELBOW_ANGLE
#define D_STRING_ELBOW_ANGLE
#define G_STRING_ELBOW_ANGLE

// Shoulder Joint Angles corresponding to the Violin string
// ------------------------------------------------------
#define E_STRING_SHOULDER_ANGLE
#define A_STRING_SHOULDER_ANGLE
#define D_STRING_SHOULDER_ANGLE
#define G_STRING_SHOULDER_ANGLE

// +------------------+
// | Global Variables |
// +------------------+

int val = 0;
int wrist_angle = 0;
int elbow_angle = 0;
int shoulder_angle = 0;

Servo wrist_servo;
Servo elbow_servo;
Servo shoulder_servo;


void setup() {
  // put your setup code here, to run once:
  Serial.begin(9600);
  pinMode(GPIO1, INPUT);
  pinMode(GPIO2, INPUT);

  pinMode(8, OUTPUT);
  pinMode(9, OUTPUT);
  pinMode(10, OUTPUT);
  pinMode(11, OUTPUT);

  wrist_servo.attach(2);
  elbow_servo.attach(3);
  shoulder_servo.attach(4);
}

int stateMachine() {
  //val = digitalRead(GPIO1);
  if (digitalRead(GPIO1) == 1) {
    Serial.println("c");
    return 1;
  } else if (digitalRead(GPIO2) == 1) {
    Serial.println("c#");
    return 2;
  } else if (digitalRead(GPIO3) == 1) {
    Serial.println("d");
    return 3;
  } else if (digitalRead(GPIO4) == 1) {
    Serial.println("d#");
    return 4;
  } else if (digitalRead(GPIO5) == 1) {
    Serial.println("e");
    return 5;
  } else if (digitalRead(GPIO6) == 1) {
    Serial.println("f");
    return 6;
  } else if (digitalRead(GPIO7) == 1) {
    Serial.println("f#");
    return 7;
  } else if (digitalRead(GPIO8) == 1) {
    Serial.println("g");
    return 8;
  } else if (digitalRead(GPIO9) == 1) {
    Serial.println("g#");
    return 9;
  } else if (digitalRead(GPIO10) == 1) {
    Serial.println("a");
    return 10;
  } else if (digitalRead(GPIO11) == 1) {
    Serial.println("a#");
    return 11;
  } else if (digitalRead(GPIO12) == 1) {
    Serial.println("b");
    return 12;
  }
}

void transmitt(int hex_input) {
 switch(hex_input) {
    case 0: 
      digitalWrite(8, 0);
      digitalWrite(9, 0);
      digitalWrite(10, 0);
      digitalWrite(11, 0);
      break;
    case 1: 
      digitalWrite(8, 1);
      digitalWrite(9, 0);
      digitalWrite(10, 0);
      digitalWrite(11, 0);
      break;
    case 2: 
      digitalWrite(8, 0);
      digitalWrite(9, 1);
      digitalWrite(10, 0);
      digitalWrite(11, 0);
      break;
    case 3: 
      digitalWrite(8, 1);
      digitalWrite(9, 1);
      digitalWrite(10, 0);
      digitalWrite(11, 0);
      break;
    case 4: 
      digitalWrite(8, 0);
      digitalWrite(9, 0);
      digitalWrite(10, 1);
      digitalWrite(11, 0);
      break;
    case 5: 
      digitalWrite(8, 1);
      digitalWrite(9, 0);
      digitalWrite(10, 1);
      digitalWrite(11, 0);
      break;
    case 6: 
      digitalWrite(8, 0);
      digitalWrite(9, 1);
      digitalWrite(10, 1);
      digitalWrite(11, 0);
      break;
    case 7: 
      digitalWrite(8, 1);
      digitalWrite(9, 1);
      digitalWrite(10, 1);
      digitalWrite(11, 0);
      break;
    case 8: 
      digitalWrite(8, 0);
      digitalWrite(9, 0);
      digitalWrite(10, 0);
      digitalWrite(11, 1);
      break;
    case 9: 
      digitalWrite(8, 1);
      digitalWrite(9, 0);
      digitalWrite(10, 0);
      digitalWrite(11, 1);
      break;
    case 10: 
      digitalWrite(8, 0);
      digitalWrite(9, 1);
      digitalWrite(10, 0);
      digitalWrite(11, 1);
      break;
    case 11: 
      digitalWrite(8, 1);
      digitalWrite(9, 1);
      digitalWrite(10, 0);
      digitalWrite(11, 1);
      break;
    case 12: 
      digitalWrite(8, 0);
      digitalWrite(9, 0);
      digitalWrite(10, 1);
      digitalWrite(11, 1);
      break;
    case 13: 
      digitalWrite(8, 1);
      digitalWrite(9, 0);
      digitalWrite(10, 1);
      digitalWrite(11, 1);
      break;
    case 14: 
      digitalWrite(8, 0);
      digitalWrite(9, 1);
      digitalWrite(10, 1);
      digitalWrite(11, 1);
      break;
    case 15: 
      digitalWrite(8, 1);
      digitalWrite(9, 1);
      digitalWrite(10, 1);
      digitalWrite(11, 1);
      break;
  }
}

void moveMechatronicArm() {
  wrist_angle = wrist_servo.read();
  elbow_angle = elbow_servo.read();
  shoulder_angle = shoulder_servo.read();
  //Serial.print("wrist_angle: " + wrist_angle + " | elbow_angle: " + elbow_angle + " | shoulder_angle: " + shoulder_angle);
  /*Serial.print("wrist_angle: ");
  Serial.print(wrist_servo.read());
  Serial.print(" | elbow_angle: ");
  Serial.print(elbow_servo.read());
  Serial.print(" | shoulder_angle: ");
  Serial.println(shoulder_servo.read());*/
}


void loop() {
  // put your main code here, to run repeatedly:
  transmitt(stateMachine());
  //moveMechatronicArm();
  delay(100);
}

/*
if(val == 1) {
    digitalWrite(13, 1);
  } else {
    digitalWrite(13, 0);
  }
  delay(500);
*/

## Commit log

2023-10-05 Scaling Down Main Box
    [Box.SLDPRT]
2023-10-05 Mechanical Update
    [Arm.SLDPRT, Arm_x.SLDPRT, Biceps(2).SLDPRT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]
2023-10-12 renamed the PCB Folder to Electrical
    [MainBoard.brd, MainBoard.sch, PCB_PinsVoltages.xlsx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]
2023-10-31 Created a Hardware and Software functionality test via C++ program that runs on an Arduino Mega 2560. This program takes in 12 Digital GPIO inputs from a Piano Keyboard model with 12 pushbuttons and 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

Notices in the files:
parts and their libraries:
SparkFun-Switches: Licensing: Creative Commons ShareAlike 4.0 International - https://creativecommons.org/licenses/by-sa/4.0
